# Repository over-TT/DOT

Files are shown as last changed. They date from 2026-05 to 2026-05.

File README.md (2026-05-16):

# DOT

3D printed 12-DOF quadruped robot. ESP32, MG90S servos.
<p align="center">
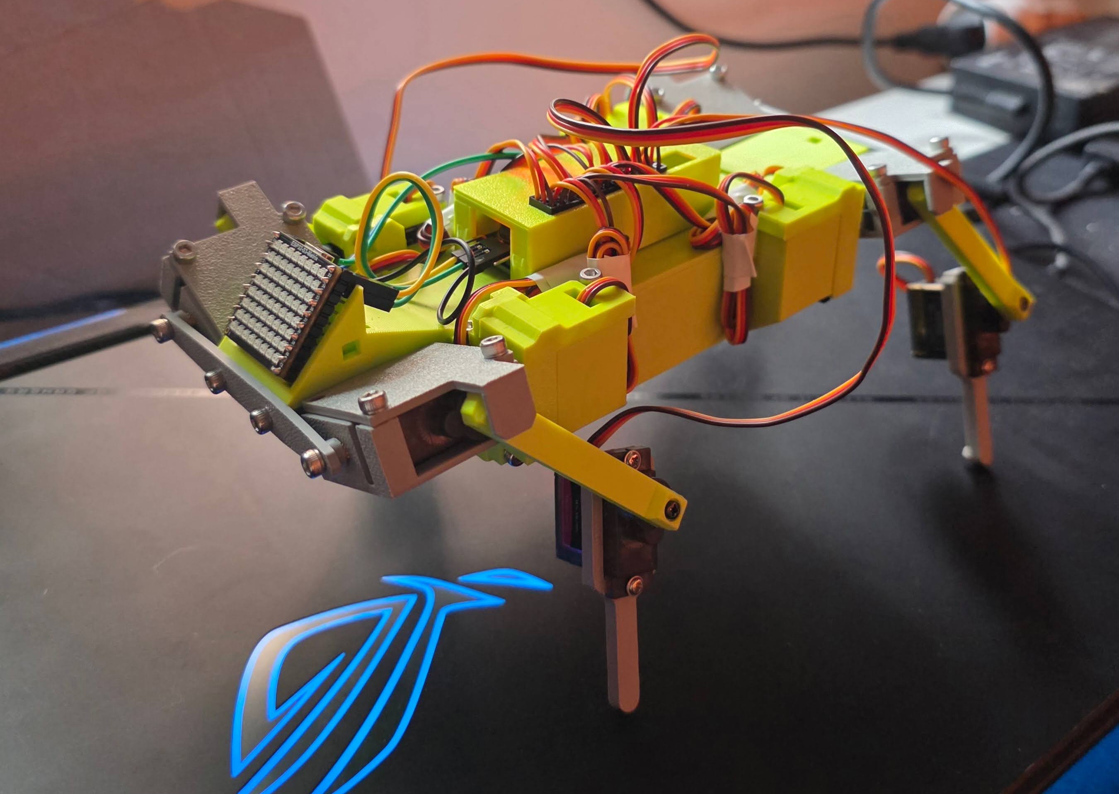
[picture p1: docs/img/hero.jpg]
Rock RC car
  
</p>
**Status:** v1.0 bring-up. IK works on single legs. Full walking is unreliable, debugging.

---

## Current status

- [x] CAD v1 printed
- [x] Servo calibration sketch
- [x] Single-leg IK test
- [ ] Stable standing pose
- [ ] Crawl gait
- [ ] IMU feedback
- [ ] URDF / Isaac Sim model

---

## Repo

- `firmware/dot_calibrate/` — sets every servo to a single angle. Used for assembly and inversion check.
- `firmware/dot_ik_test/` — commands one leg to a target position via IK.
- `CAD/3mf/` — printable files
- `CAD/step/` — coming later
- `docs/kinematics.md` — FK + IK derivations
- `docs/wiring.md` — wiring reference
- `docs/calibration.md` — servo zeroing procedure

---

## Parts

**Electronics**

- 12x MG90S micro servo ([Waveshare](https://www.waveshare.com/mg90s-servo.htm))
- Waveshare ESP32-S3-Matrix — ESP32-S3, 8x8 RGB face, onboard QMI8658 6-axis IMU
- PCA9685 16-channel PWM driver
- 2x18650 Lithium Battery Shield, 5V 3A / 3V 1A out
- 2x 18650 Li-ion cell
- Wire

**3D printed**

Each 3MF contains the right part count and mirroring. Print each file once.

- `body`
- `body_top`
- `front_mount`
- `hip_servo_holder`
- `upper_servo_holder`
- `upper_servo_cover`
- `leg_upper`
- `leg_lower`
- `pca9685_cover`

PLA. Settings embedded in each 3MF (Bambu Studio).

**Hardware**

- M3 screws
- M3 heat-set inserts

---

## Wiring

ESP32-S3-Matrix → PCA9685 over I2C. Servos plug into PCA9685 channels 0–11. Full pinout in [docs/wiring.md](docs/wiring.md).

```
PCA9685 SDA -> ESP32 GPIO 34
PCA9685 SCL -> ESP32 GPIO 33
PCA9685 VCC -> 3.3V
GND         -> GND
Servo V+    -> battery shield 5V rail
```

Don't power servos off the ESP32's 5V.
---

## Flash

Arduino IDE, `esp32` core 2.0+ from Boards Manager.

Libraries:

- Adafruit PWM Servo Driver Library
- Wire (built-in)

Board: `ESP32S3 Dev Module`. Upload over USB-C.

---

## Assemble

Calibrate before mounting any of the legs. Otherwise the software's 90° won't match the physical 90° and the IK will be off. Full procedure in [docs/calibration.md](docs/calibration.md).

1. Flash `firmware/dot_calibrate/` — sets every servo to the angle defined at the top of the sketch.
2. Set the angle to 90°, run it, watch all 12 servos.
3. Some servos end up mounted mirrored. Note which ones rotate the wrong way, add their indices to the `INVERTED` list at the top of the sketch, reflash.
4. Re-run. All servos should now move the right direction for a positive angle change.
5. With servos still holding 90°, mount the leg parts. Leg link first, then knee link. Tighten the horn screws while the leg is in its neutral pose.
6. Repeat for all four legs.

---

## Math

Forward and inverse kinematics for the 3R leg chain. Derivations in [`docs/kinematics.md`](docs/kinematics.md).

Validated in Desmos:

- [FK](https://www.desmos.com/3d/erax4k9wia)
- [IK](https://www.desmos.com/3d/gpihu2vkmm)

In the Desmos files, `L1` is the leg length and `O` is the ab/ad offset. The rest of the variables are self-evident. Better diagrams will come with the full derivation in `docs/kinematics.md`.

Still to do: Jacobian, workspace analysis, foot trajectories, parameterized gait.

---

## TODO

- [ ] Hero photo + demo video
- [ ] Wiring diagram
- [ ] Face animations on the LED matrix
- [ ] Fix walking
- [ ] Walking gait code
- [ ] Better servos for hip and knee
- [ ] Cable cover design — maybe
- [ ] Jacobian + workspace
- [ ] Foot trajectory generation
- [ ] Parameterized gait controller
- [ ] IMU in the control loop
- [ ] URDF
- [ ] Isaac Lab pipeline
- [ ] Sim-to-real writeup

---

## License

- Code (`firmware/`): MIT — see [LICENSE](LICENSE)
- CAD (`CAD/`): CC BY-SA 4.0 — see [CAD/LICENSE](CAD/LICENSE)

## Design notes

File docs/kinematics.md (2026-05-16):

# Kinematics

Forward and inverse kinematics for DOT's 3R leg chain.

The working math is also in Desmos:

- [FK](https://www.desmos.com/3d/erax4k9wia)
- [IK](https://www.desmos.com/3d/gpihu2vkmm)

Full written derivation with diagrams is still coming. What follows is the conventions and the IK pipeline as implemented in `firmware/dot_ik_test/`.

---

## Coordinate system

Right-handed, body frame, hip joint as the origin for each leg.

- **X** — forward / back. Positive X points forward.
- **Y** — left / right. Positive Y points outward from the body (away from the spine) once the IK has mirrored the left side. See "Left/right mirroring" below.
- **Z** — up / down. Positive Z points up. Negative Z is where the foot lives.

Units are arbitrary as long as they match `L1` and `L2`. The current sketch uses centimeters.

---

## Leg geometry

Each leg is a 3R chain: hip (ab/ad), upper leg, knee.

- `O` — hip side offset. Distance from the body centerline along Y to the upper-leg pivot. Signed; currently `-0.6`.
- `L1` — upper leg length. From the upper-leg pivot to the knee. Currently `5.0`.
- `L2` — lower leg length. From the knee to the foot tip. Currently `5.0`.

`L1 == L2` simplifies the workspace but is not required.

---

## Servo mapping

Each leg has three servos, indexed in the firmware as `{hip, upper, knee}`:

- `g` — side hip servo. Rotates the upper-leg pivot about the X axis.
- `a` — upper leg servo. Pitches the upper leg about the Y axis at the hip.
- `t` — knee servo. Bends the lower leg about the Y axis at the knee.

All three are MG90S, driven by a PCA9685. Logical angle `90°` is neutral. Some servos are mounted mirrored — those are flipped in software via `REVERSED_SERVOS`.

---

## Left/right mirroring

The IK is solved in a "right-side" frame and then mirrored for the left side.

In code:

```cpp
float yLocal = left ? -y : y;
```

That means the caller can use the same `(x, y, z)` semantics for any leg ("positive Y is outward") and the IK takes care of the sign. The `left` flag is set per leg in the dispatch:

- front left, back left → `isLeft = true`
- front right, back right → `isLeft = false`

---

## IK pipeline

1. **Rotate target into the leg plane.**
   Compute `g` from the Y-Z view using the hip offset `O`:

   ```text
   r1 = sqrt(y² + z²)
   c1 = O / r1            (clamped to [-1, 1])
   P  = atan2(y, z)
   g  = P + acos(c1)
   ```

2. **Project the target into the 2D plane of the leg.**

   ```text
   x2 =  x
   z2 = -y · cos(g) + z · sin(g)
   d  = sqrt(x2² + z2²)
   ```

3. **Check reachability.**
   Bail out if `d > L1 + L2` or `d < |L1 − L2|`.

4. **Solve the 2-link triangle.**

   ```text
   c2 = (L1² + L2² − d²) / (2·L1·L2)
   kneeInner = acos(c2)
   t = π − (kneeInner − π/2)

   c3 = (L1² + d² − L2²) / (2·L1·d)
   beta = acos(c3)
   p    = atan2(z2, x2)
   a    = π − p − beta
   ```

5. **Convert math angles to servo angles.**
   Radians → degrees, then apply mechanical offsets and inversions in `writeServoLogical()`:

   ```text
   logical = mathAngle + servoOffset[i]
   actual  = isReversed(i) ? (180 − logical) : logical
   pulse   = map(actual, 0, 180, SERVO_MIN, SERVO_MAX)
   ```

   `legGeometryOffset[i]` is added on top of the math result for `leg[1]` (upper) and `leg[2]` (knee) to absorb residual mechanical alignment.

---

## Variables

| Symbol | Meaning |
|---|---|
| `X, Y, Z` | foot target in the leg's body frame |
| `O` | hip side offset (signed) |
| `L1` | upper leg length |
| `L2` | lower leg length |
| `g` | ab/ad (side hip) joint angle |
| `a` | upper-leg pitch joint angle |
| `t` | knee joint angle |

---

## Status

- [x] FK closed-form
- [x] IK closed-form
- [x] Left/right mirroring in code
- [ ] Validated against hardware end-to-end
- [ ] Jacobian
- [ ] Workspace analysis (straight-leg geometry)
- [ ] Written derivation with diagrams

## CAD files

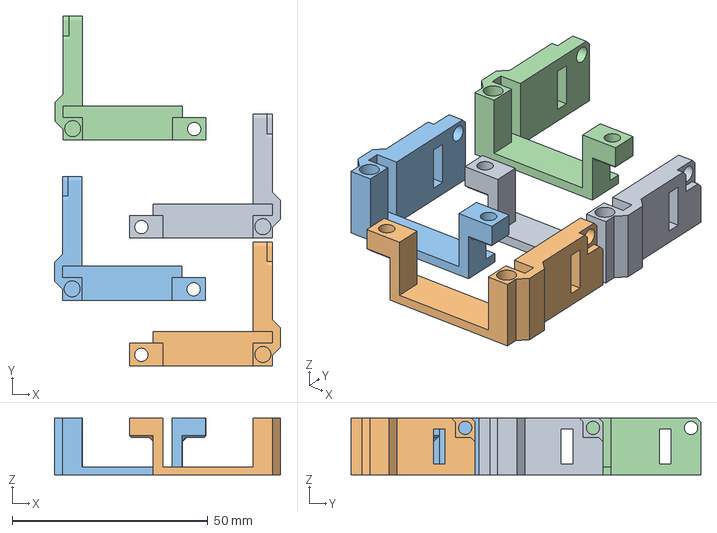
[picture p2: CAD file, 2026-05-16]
CAD/3mf/hip_servo_holder.3mf
57.7 x 89.2 x 14.5 mm

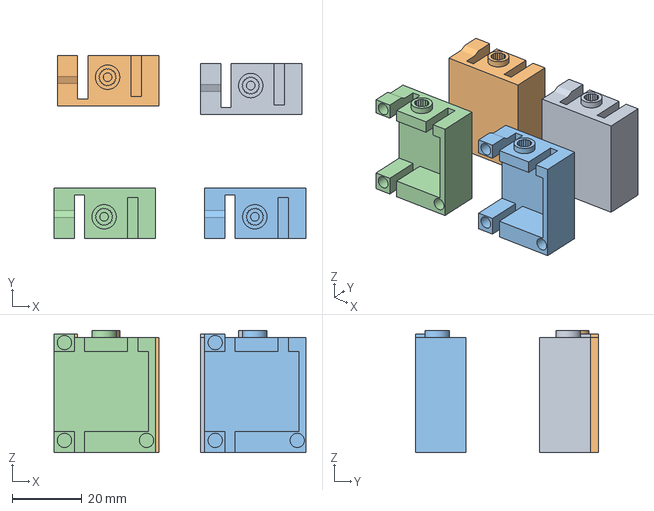
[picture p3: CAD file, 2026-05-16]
CAD/3mf/upper_servo_holder.3mf
72.2 x 52.5 x 35.0 mm

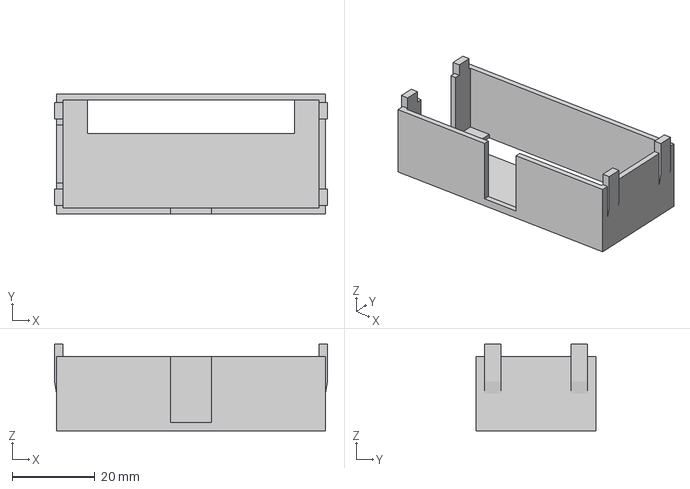
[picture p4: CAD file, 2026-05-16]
CAD/3mf/pca9685_cover.3mf
66.0 x 29.0 x 21.0 mm

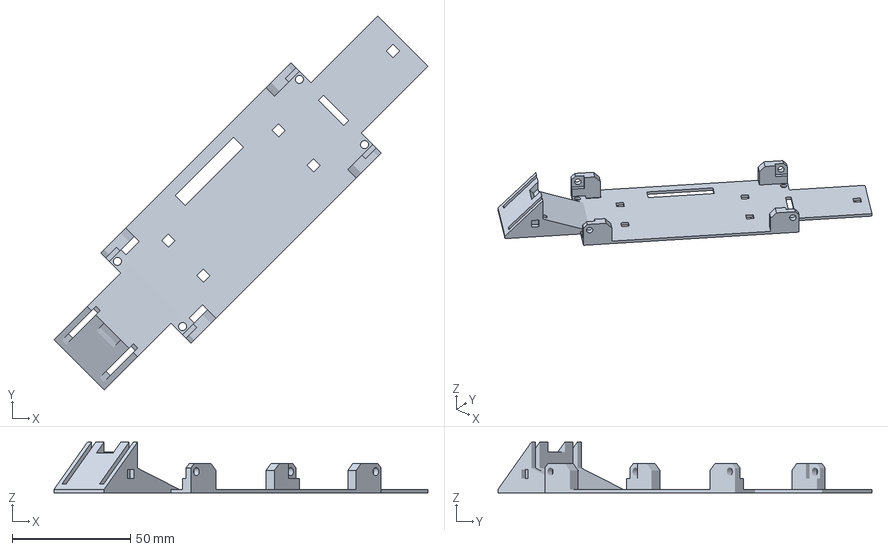
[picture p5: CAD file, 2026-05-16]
CAD/3mf/body_top.3mf
158.4 x 158.4 x 21.5 mm

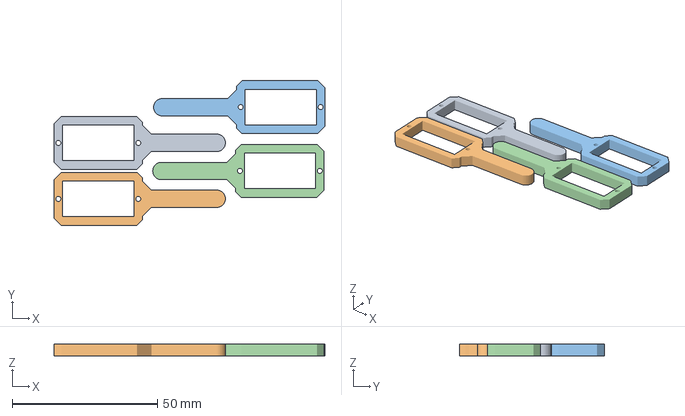
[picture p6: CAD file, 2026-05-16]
CAD/3mf/leg_lower.3mf
93.2 x 49.8 x 4.00 mm

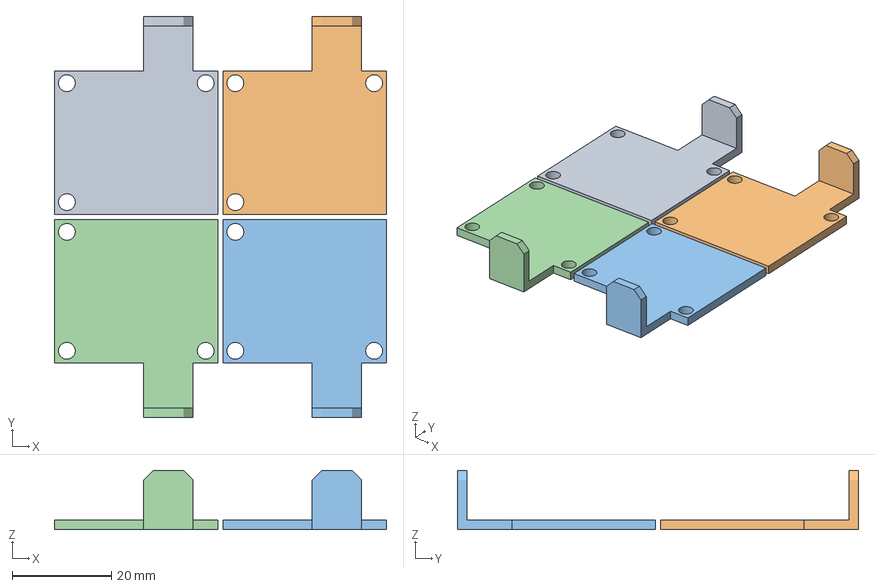
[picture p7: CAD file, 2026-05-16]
CAD/3mf/upper_servo_cover.3mf
67.0 x 81.0 x 12.0 mm

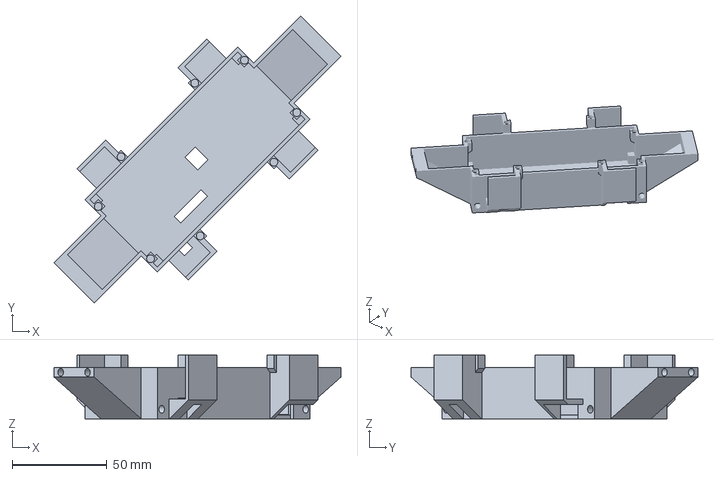
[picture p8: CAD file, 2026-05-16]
CAD/3mf/body.3mf
151.3 x 151.3 x 33.5 mm

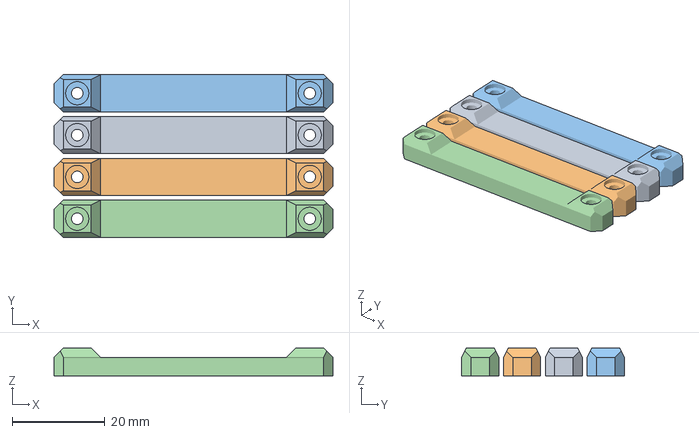
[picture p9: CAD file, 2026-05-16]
CAD/3mf/leg_upper.3mf
60.0 x 35.0 x 6.00 mm

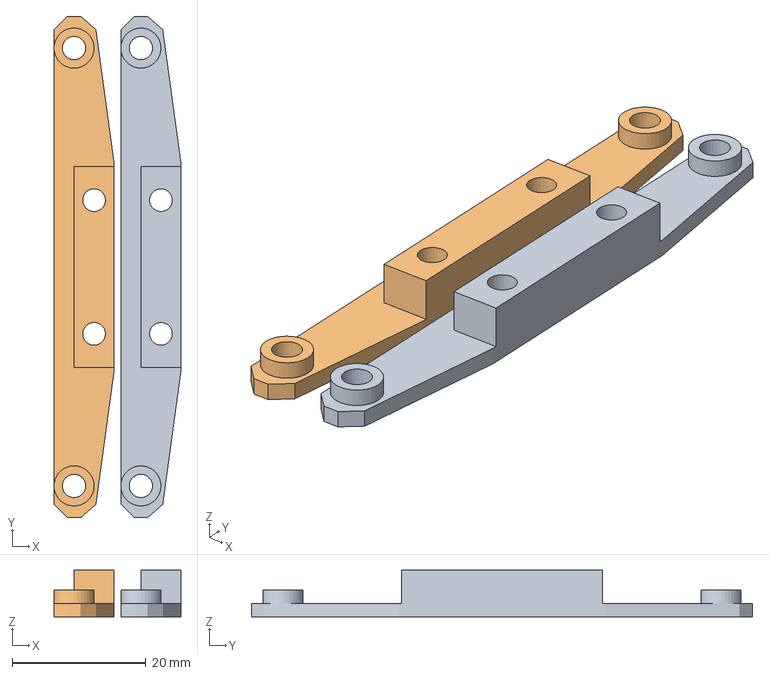
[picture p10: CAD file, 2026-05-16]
CAD/3mf/front_mount.3mf
19.0 x 75.0 x 7.00 mm

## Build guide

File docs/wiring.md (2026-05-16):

# Wiring

DOT's electronics in one place. Diagram still TODO.

---

## Bus

ESP32-S3-Matrix ↔ PCA9685 over I2C.

| Signal | ESP32-S3-Matrix pin | PCA9685 pin |
|---|---|---|
| SDA | GPIO 34 | SDA |
| SCL | GPIO 33 | SCL |
| VCC | 3.3 V | VCC |
| GND | GND | GND |

The I2C pins are set in code at `firmware/dot_ik_test/dot_ik_test.ino` via `SDA_PIN` / `SCL_PIN`. If you change them in hardware, change them there too.

PCA9685 I2C address: `0x40` (default, all address-select pads open).

---

## Power

| Source | Goes to |
|---|---|
| 2×18650 battery shield, 5 V 3 A rail | PCA9685 V+ screw terminal (servo rail) |
| 2×18650 battery shield, 3 V 1 A rail | ESP32-S3-Matrix 5V/USB pin (via the shield's regulated output — *not* shared with servos) |
| Common ground | battery shield GND ↔ PCA9685 GND ↔ ESP32 GND |

**Do not** power the servos off the ESP32's 5 V pin. Twelve MG90S under load will brown out the board, the IMU will glitch, and the I2C bus will go down with it.

---

## Servo channel map

PCA9685 channels 0–11. Channel numbers match `firmware/dot_ik_test/dot_ik_test.ino` `FRONT_LEFT` / `FRONT_RIGHT` / `BACK_LEFT` / `BACK_RIGHT` arrays.

| Leg | Hip (side) | Upper leg | Knee/foot |
|---|---|---|---|
| Front left  | 0 | 4 | 8  |
| Front right | 1 | 5 | 9  |
| Back left | 2 | 6 | 10 |
| Back right  | 3 | 7 | 11 |

Reversed (mounted mirrored) servos are listed in the firmware constant `REVERSED_SERVOS`. Current value: `{0, 2, 4, 6, 9, 11}`. Update there if you remount.

---

## TODO

- [ ] Wiring diagram (image)
- [ ] Photo of the assembled wire loom
- [ ] Connector / pinout reference for the battery shield

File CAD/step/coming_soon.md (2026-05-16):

# STEP exports

STEP files for each part are not yet exported.

Until they land here, the source `.3mf` files in [`CAD/3mf/`](../3mf) contain the geometry and slicing settings (Bambu Studio).

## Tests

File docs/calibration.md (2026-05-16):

# Calibration

Before mounting any leg parts, every servo's software 90° must match its physical neutral. Otherwise IK is meaningless.

---

## Required

- Assembled body with all 12 MG90S servos seated in their printed mounts, **horns not yet attached**.
- PCA9685 wired up and powered (see [wiring.md](wiring.md)).
- `firmware/dot_calibrate/` flashed.

---

## Procedure

1. Open `firmware/dot_calibrate/dot_calibrate.ino`. Make sure the top-of-file angle is set to **90°**.
2. Flash and let all 12 servos drive to their neutral position.
3. Without forcing them, tap each servo horn output gently to confirm it's holding. Cut power if any servo is buzzing hard against a mechanical stop — that one's offset is wrong and needs to be corrected before continuing.
4. **Identify reversed servos.** Increase the test angle (e.g. 90 → 120) and reflash. Watch which servos rotate the *wrong* way relative to the leg's intended motion. Add those servo indices to `REVERSED_SERVOS` at the top of the sketch.
5. Reflash with the angle back at 90°. Confirm every servo is at neutral *and* rotating the intended direction when you nudge the angle up.
6. **Mount the legs at 90°.** Upper-leg first, then knee. Tighten the horn screws while the servo is still holding neutral. If you let the horn slip, the leg's zero will be off and you'll be chasing it through `servoOffset[]` forever.
7. Repeat for all four legs.
8. (Optional) Fine-tune `servoOffset[]` in `dot_ik_test/` for any residual asymmetry. Single-digit degrees only — anything more means the horn is on a wrong spline.

When this is done, the software's 90° matches the hardware's 90°, and the IK will mean what it says.

---

## Notes

- `legGeometryOffset[]` exists for the upper-leg and knee servos specifically and is applied on top of the IK output in `moveLegToXYZ()`. Use it for systematic geometric tweaks (e.g. all knees are biased 3° forward), not for fixing a single mismounted horn.
- Servo target angles in `dot_ik_test/` are clipped to **45°–135°**. Anything outside is silently clamped. Keep poses inside that window or change the clamp in `setServoTarget()`.

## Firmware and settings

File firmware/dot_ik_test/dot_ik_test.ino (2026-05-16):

#include <Wire.h>
#include <Adafruit_PWMServoDriver.h>
#include <math.h>

Adafruit_PWMServoDriver pca = Adafruit_PWMServoDriver(0x40);

// =============================
// DOT SERVO + IK SETUP
// =============================

// ESP32 I2C pins connected to the PCA9685
const int SDA_PIN = 34;
const int SCL_PIN = 33;

// PCA9685 pulse range for the servos
const int SERVO_MIN = 100;
const int SERVO_MAX = 520;

const int NUM_SERVOS = 12;

// Servos that are mounted backwards
// Add servo ports here if they move in the wrong direction
const int REVERSED_SERVOS[] = {0, 2, 4, 6, 9, 11};
const int REVERSED_SERVO_COUNT = sizeof(REVERSED_SERVOS) / sizeof(REVERSED_SERVOS[0]);

// Smoothing settings
const int STEP_SIZE = 1;
const int UPDATE_INTERVAL = 12;

// Turn this on only if you want the Serial Monitor to become a waterfall of numbers
const bool PRINT_IK_DEBUG = false;

// Leg servo groups: {hip side, upper leg, foot/knee}
const int BACK_RIGHT[3]  = {3, 7, 11};
const int FRONT_RIGHT[3] = {1, 5, 9};
const int BACK_LEFT[3]   = {2, 6, 10};
const int FRONT_LEFT[3]  = {0, 4, 8};

// Offset for each servo to fix mechanical alignment
int servoOffset[NUM_SERVOS] = {
  0, 0, 0, 0,
  0, 0, 0, 0,
  0, 0, 0, 0
};

// Extra geometry offsets for upper leg and knee tuning.
// Applied to leg[1] (upper) and leg[2] (knee/foot) in moveLegToXYZ().
int legGeometryOffset[NUM_SERVOS] = {
  0, 0, 0, 0,
  0, 0, 0, 0,
  0, 0, 0, 0
};

int currentAngle[NUM_SERVOS];
int targetAngle[NUM_SERVOS];

unsigned long lastUpdate = 0;

// =============================
// IK MATH
// =============================

struct IKResult {
  float g;      // side hip angle
  float a;      // upper leg angle
  float t;      // knee angle
  bool valid;   // false if point cannot be reached
};

IKResult ik(float x, float y, float z, bool left) {
  IKResult result;

  result.g = 0;
  result.a = 0;
  result.t = 0;
  result.valid = false;

  // Robot dimensions
  const float o  = -0.6f;  // hip offset
  const float l1 = 5.0f;   // upper leg length
  const float l2 = 5.0f;   // lower leg length

  // Mirror Y for the left side so a positive Y always means "outward from the body"
  float yLocal = left ? -y : y;

  // Distance in the Y-Z view
  float r1 = sqrtf(yLocal * yLocal + z * z);

  // Avoid divide-by-zero
  if (r1 < 0.0001f) {
    return result;
  }

  // First side angle
  float c1 = o / r1;
  if (c1 > 1.0f) c1 = 1.0f;
  if (c1 < -1.0f) c1 = -1.0f;

  float P = atan2f(yLocal, z);
  float g = P + acosf(c1);

  // Rotate target into the 2D plane of the leg
  float x2 = x;
  float z2 = -yLocal * cosf(g) + z * sinf(g);

  // Distance from hip joint to target in the 2D leg plane
  float d = sqrtf(x2 * x2 + z2 * z2);

  // Check if target is reachable
  if (d > l1 + l2) {
    return result;
  }

  if (d < fabsf(l1 - l2)) {
    return result;
  }

  // Solve the 2-link leg triangle
  float c2 = (l1 * l1 + l2 * l2 - d * d) / (2.0f * l1 * l2);
  if (c2 > 1.0f) c2 = 1.0f;
  if (c2 < -1.0f) c2 = -1.0f;

  float kneeInner = acosf(c2);
  float t = PI - (kneeInner - PI / 2);

  float c3 = (l1 * l1 + d * d - l2 * l2) / (2.0f * l1 * d);
  if (c3 > 1.0f) c3 = 1.0f;
  if (c3 < -1.0f) c3 = -1.0f;

  float beta = acosf(c3);
  float p = atan2f(z2, x2);
  float a = PI - p - beta;

  // Convert radians to degrees
  result.g = g * 180.0f / PI;
  result.a = a * 180.0f / PI;
  result.t = t * 180.0f / PI;
  result.valid = true;

  return result;
}

// =============================
// SERVO CONTROL
// =============================

bool isReversed(int servo) {
  for (int i = 0; i < REVERSED_SERVO_COUNT; i++) {
    if (REVERSED_SERVOS[i] == servo) {
      return true;
    }
  }

  return false;
}

int angleToPulse(int angle) {
  angle = constrain(angle, 0, 180);
  return map(angle, 0, 180, SERVO_MIN, SERVO_MAX);
}

void writeServoLogical(int servo, int logicalAngle) {
  if (servo < 0 || servo >= NUM_SERVOS) return;

  logicalAngle += servoOffset[servo];
  logicalAngle = constrain(logicalAngle, 0, 180);

  int actualAngle = logicalAngle;

  if (isReversed(servo)) {
    actualAngle = 180 - logicalAngle;
  }

  int pulse = angleToPulse(actualAngle);
  pca.setPWM(servo, 0, pulse);
}

void setServoTarget(int servo, int angle) {
  if (servo < 0 || servo >= NUM_SERVOS) return;

  targetAngle[servo] = constrain(angle, 45, 135);
}

void updateServosSmooth() {
  if (millis() - lastUpdate < UPDATE_INTERVAL) return;

  lastUpdate = millis();

  for (int servo = 0; servo < NUM_SERVOS; servo++) {
    if (currentAngle[servo] < targetAngle[servo]) {
      currentAngle[servo] += STEP_SIZE;

      if (currentAngle[servo] > targetAngle[servo]) {
        currentAngle[servo] = targetAngle[servo];
      }

      writeServoLogical(servo, currentAngle[servo]);
    }
    else if (currentAngle[servo] > targetAngle[servo]) {
      currentAngle[servo] -= STEP_SIZE;

      if (currentAngle[servo] < targetAngle[servo]) {
        currentAngle[servo] = targetAngle[servo];
      }

      writeServoLogical(servo, currentAngle[servo]);
    }
  }
}

// =============================
// BASIC SERVO GROUP MOVES
// =============================

void moveAllHipServos(int angle) {
  setServoTarget(0, angle);
  setServoTarget(1, angle);
  setServoTarget(2, angle);
  setServoTarget(3, angle);
}

void moveAllLegServos(int angle) {
  setServoTarget(4, angle);
  setServoTarget(5, angle);
  setServoTarget(6, angle);
  setServoTarget(7, angle);
}

void moveAllFeetServos(int angle) {
  setServoTarget(8, angle);
  setServoTarget(9, angle);
  setServoTarget(10, angle);
  setServoTarget(11, angle);
}

void standPose() {
  moveAllHipServos(110);
  moveAllLegServos(45);
  moveAllFeetServos(90);
}

// =============================
// MOVE ONE LEG USING IK
// =============================

void moveLegToXYZ(const int leg[3], float x, float y, float z, bool left) {
  IKResult angles = ik(x, y, z, left);

  if (!angles.valid) {
    Serial.print("IK failed for x=");
    Serial.print(x);
    Serial.print(" y=");
    Serial.print(y);
    Serial.print(" z=");
    Serial.println(z);
    return;
  }

  int hipTarget  = (int)angles.g;
  int legTarget  = (int)angles.a + legGeometryOffset[leg[1]];
  int footTarget = (int)angles.t + legGeometryOffset[leg[2]];

  if (PRINT_IK_DEBUG) {
    Serial.print("RAW IK -> g=");
    Serial.print(angles.g);
    Serial.print("  a=");
    Serial.print(angles.a);
    Serial.print("  t=");
    Serial.println(angles.t);

    Serial.print("TARGETS -> hip=");
    Serial.print(hipTarget);
    Serial.print("  leg=");
    Serial.print(legTarget);
    Serial.print("  foot=");
    Serial.println(footTarget);
  }

  setServoTarget(leg[0], hipTarget);
  setServoTarget(leg[1], legTarget);
  setServoTarget(leg[2], footTarget);
}

// =============================
// SETUP
// =============================

void setup() {
  Serial.begin(115200);

  Wire.begin(SDA_PIN, SCL_PIN);

  pca.begin();
  pca.setPWMFreq(50);

  delay(500);

  for (int i = 0; i < NUM_SERVOS; i++) {
    currentAngle[i] = 90;
    targetAngle[i] = 90;
    writeServoLogical(i, 90);
  }

  Serial.println();
  Serial.println("=== DOT SERVO / IK CONTROL ===");
  Serial.println();
  Serial.println("Basic test commands:");
  Serial.println("  0  -> all hips to 45");
  Serial.println("  1  -> all hips to 90");
  Serial.println("  2  -> all hips to 135");
  Serial.println("  3  -> all upper-leg servos to 45");
  Serial.println("  4  -> all upper-leg servos to 90");
  Serial.println("  5  -> all upper-leg servos to 135");
  Serial.println("  6  -> all foot/knee servos to 45");
  Serial.println("  7  -> all foot/knee servos to 90");
  Serial.println("  8  -> all foot/knee servos to 135");
  Serial.println("  9  -> stand pose");
  Serial.println();
  Serial.println("IK command:");
  Serial.println("  ik <leg> <x> <y> <z>");
  Serial.println();
  Serial.println("Leg numbers:");
  Serial.println("  0 = front left");
  Serial.println("  1 = front right");
  Serial.println("  2 = back left");
  Serial.println("  3 = back right");
  Serial.println();
  Serial.println("Example:");
  Serial.println("  ik 0 4.0 1.0 6.0");
  Serial.println();
}

// =============================
// MAIN LOOP
// =============================

void loop() {
  updateServosSmooth();

  if (Serial.available() > 0) {
    String input = Serial.readStringUntil('\n');
    input.trim();

    int legNumber;
    float x, y, z;

    if (sscanf(input.c_str(), "ik %d %f %f %f", &legNumber, &x, &y, &z) == 4) {
      const int* chosenLeg = nullptr;
      bool isLeft = false;
      const char* legName = "";

      if (legNumber == 0) {
        chosenLeg = FRONT_LEFT;
        isLeft = true;
        legName = "front left";
      }
      else if (legNumber == 1) {
        chosenLeg = FRONT_RIGHT;
        isLeft = false;
        legName = "front right";
      }
      else if (legNumber == 2) {
        chosenLeg = BACK_LEFT;
        isLeft = true;
        legName = "back left";
      }
      else if (legNumber == 3) {
        chosenLeg = BACK_RIGHT;
        isLeft = false;
        legName = "back right";
      }

      if (chosenLeg != nullptr) {
        Serial.print("Moving ");
        Serial.print(legName);
        Serial.print(" to x=");
        Serial.print(x);
        Serial.print(" y=");
        Serial.print(y);
        Serial.print(" z=");
        Serial.println(z);

        moveLegToXYZ(chosenLeg, x, y, z, isLeft);
      }
      else {
        Serial.println("Bad leg number. Use 0, 1, 2, or 3.");
      }
    }
    else {
      int command = input.toInt();

      if (command == 0) {
        moveAllHipServos(45);
      }
      else if (command == 1) {
        moveAllHipServos(90);
      }
      else if (command == 2) {
        moveAllHipServos(135);
      }
      else if (command == 3) {
        moveAllLegServos(45);
      }
      else if (command == 4) {
        moveAllLegServos(90);
      }
      else if (command == 5) {
        moveAllLegServos(135);
      }
      else if (command == 6) {
        moveAllFeetServos(45);
      }
      else if (command == 7) {
        moveAllFeetServos(90);
      }
      else if (command == 8) {
        moveAllFeetServos(135);
      }
      else if (command == 9) {
        standPose();
      }
    }
  }
}

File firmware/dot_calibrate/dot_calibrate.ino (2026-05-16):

#include <Wire.h>
#include <Adafruit_PWMServoDriver.h>

Adafruit_PWMServoDriver pca = Adafruit_PWMServoDriver(0x40);

// =============================
// DOT SERVO SETUP
// =============================

// ESP32 I2C pins connected to the PCA9685
const int SDA_PIN = 34;
const int SCL_PIN = 33;

// PCA9685 pulse range for the servos
const int SERVO_MIN = 100;
const int SERVO_MAX = 520;


const int NUM_SERVOS = 12;

// Servos that are mounted backwards
// Add servo ports here if they move in the wrong direction
const int INVERTED_SERVOS[] = {0, 2, 4, 6, 9, 11};
const int INVERTED_SERVO_COUNT = sizeof(INVERTED_SERVOS) / sizeof(INVERTED_SERVOS[0]);

// Servo groups
const int HIP_SERVOS[]  = {0, 1, 2, 3};
const int LEG_SERVOS[]  = {4, 5, 6, 7};
const int FEET_SERVOS[] = {8, 9, 10, 11};

// Smoothing settings
const int STEP_SIZE = 2;
const int UPDATE_INTERVAL = 15;

int currentAngle[NUM_SERVOS];
int targetAngle[NUM_SERVOS];

unsigned long lastUpdate = 0;

// Offset for each servo to fix mechanical alignment
int servoOffset[NUM_SERVOS] = {
  0, 0, 0, 0,
  0, 0, 0, 0,
  0, 0, 0, 0
};

bool isInverted(int servo) {
  for (int i = 0; i < INVERTED_SERVO_COUNT; i++) {
    if (INVERTED_SERVOS[i] == servo) {
      return true;
    }
  }
  return false;
}

int angleToPulse(int angle) {
  angle = constrain(angle, 0, 180);
  return map(angle, 0, 180, SERVO_MIN, SERVO_MAX);
}

void writeServoLogical(int servo, int logicalAngle) {
  logicalAngle += servoOffset[servo];
  logicalAngle = constrain(logicalAngle, 0, 180);

  int actualAngle = logicalAngle;

  if (isInverted(servo)) {
    actualAngle = 180 - logicalAngle;
  }

  int pulse = angleToPulse(actualAngle);
  pca.setPWM(servo, 0, pulse);
}

void setServoTarget(int servo, int angle) {
  if (servo < 0 || servo >= NUM_SERVOS) return;
  targetAngle[servo] = constrain(angle, 0, 180);
}

void updateServosSmooth() {
  if (millis() - lastUpdate < UPDATE_INTERVAL) return;
  lastUpdate = millis();

  for (int servo = 0; servo < NUM_SERVOS; servo++) {
    if (currentAngle[servo] < targetAngle[servo]) {
      currentAngle[servo] += STEP_SIZE;

      if (currentAngle[servo] > targetAngle[servo]) {
        currentAngle[servo] = targetAngle[servo];
      }

      writeServoLogical(servo, currentAngle[servo]);
    }
    else if (currentAngle[servo] > targetAngle[servo]) {
      currentAngle[servo] -= STEP_SIZE;

      if (currentAngle[servo] < targetAngle[servo]) {
        currentAngle[servo] = targetAngle[servo];
      }

      writeServoLogical(servo, currentAngle[servo]);
    }
  }
}

void moveServoGroup(const int servoList[], int servoCount, int angle) {
  for (int i = 0; i < servoCount; i++) {
    setServoTarget(servoList[i], angle);
  }
}

void moveAllHipServos(int angle) {
  moveServoGroup(HIP_SERVOS, 4, angle);
}

void moveAllLegServos(int angle) {
  moveServoGroup(LEG_SERVOS, 4, angle);
}

void moveAllFeetServos(int angle) {
  moveServoGroup(FEET_SERVOS, 4, angle);
}

void standPose() {
  moveAllHipServos(110);
  moveAllLegServos(40);
  moveAllFeetServos(90);
}

void setup() {
  Serial.begin(115200);
  Wire.begin(SDA_PIN, SCL_PIN);

  pca.begin();
  pca.setPWMFreq(50);

  delay(500);

  for (int i = 0; i < NUM_SERVOS; i++) {
    currentAngle[i] = 90;
    targetAngle[i] = 90;
    writeServoLogical(i, 90);
  }

  Serial.println("Commands:");
  Serial.println("0 -> hips 45");
  Serial.println("1 -> hips 90");
  Serial.println("2 -> hips 135");
  Serial.println("3 -> legs 45");
  Serial.println("4 -> legs 90");
  Serial.println("5 -> legs 135");
  Serial.println("6 -> feet 45");
  Serial.println("7 -> feet 90");
  Serial.println("8 -> feet 135");
  Serial.println("9 -> stand pose");
}

void loop() {
  updateServosSmooth();

  if (Serial.available() > 0) {
    String input = Serial.readStringUntil('\n');
    input.trim();

    int command = input.toInt();
    int hip_angle = -1;
    int leg_angle = -1;
    int feet_angle = -1;

    if (command == 0) {
      hip_angle = 45;
    }
    else if (command == 1) {
      hip_angle = 90;
    }
    else if (command == 2) {
      hip_angle = 135;
    }
    else if (command == 3) {
      leg_angle = 45;
    }
    else if (command == 4) {
      leg_angle = 90;
    }
    else if (command == 5) {
      leg_angle = 135;
    }
    else if (command == 6) {
      feet_angle = 45;
    }
    else if (command == 7) {
      feet_angle = 90;
    }
    else if (command == 8) {
      feet_angle = 135;
    }
    else if (command == 9) {
      standPose();
    }

    if (hip_angle != -1) {
      moveAllHipServos(hip_angle);
    }

    if (leg_angle != -1) {
      moveAllLegServos(leg_angle);
    }

    if (feet_angle != -1) {
      moveAllFeetServos(feet_angle);
    }
  }
}
